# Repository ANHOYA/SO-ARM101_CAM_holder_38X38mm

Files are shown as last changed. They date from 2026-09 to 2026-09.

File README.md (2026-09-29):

# 38 mm IMX307 Camera Mounts for SO-101 and 1/4-20 Tripods

Printable mounts for a **38 × 38 mm IMX307 USB camera board**: a wrist mount for the SO-101 follower arm and two versions of a tripod / ball-head holder with a standard 1/4-20 camera screw. Check the dimensions below before printing; the IMX307 sensor name alone does not guarantee that another camera board will fit.

## Downloads

| File | Use |
| --- | --- |
| [`SO101_wrist_IMX307_38mm.stl`](SO101_wrist_IMX307_38mm.stl) | Attaches the camera to the **SO-101 follower wrist** using the wrist's two M3 nut recesses. |
| [`Tripod_IMX307_38mm_quarter20_nut.stl`](Tripod_IMX307_38mm_quarter20_nut.stl) | **Tripod v1:** compact base; 6 mm horizontal offset to the nut axis and a 4 mm nut-pocket floor. |
| [`Tripod_IMX307_38mm_quarter20_nut_v2.stl`](Tripod_IMX307_38mm_quarter20_nut_v2.stl) | **Tripod v2:** 18 mm horizontal offset to the nut axis for more access, with a thinner 2 mm nut-pocket floor. |

All STL files use **millimetres**. Choose one mount for each camera. Both tripod versions require a separate metal **1/4-20 UNC hex nut** to provide the female thread; the printed parts have no thread. It is not compatible with an M6 nut.

## Photos

SO-101 wrist installation with the intended 38 × 38 mm camera board:

### SO-101 wrist mount

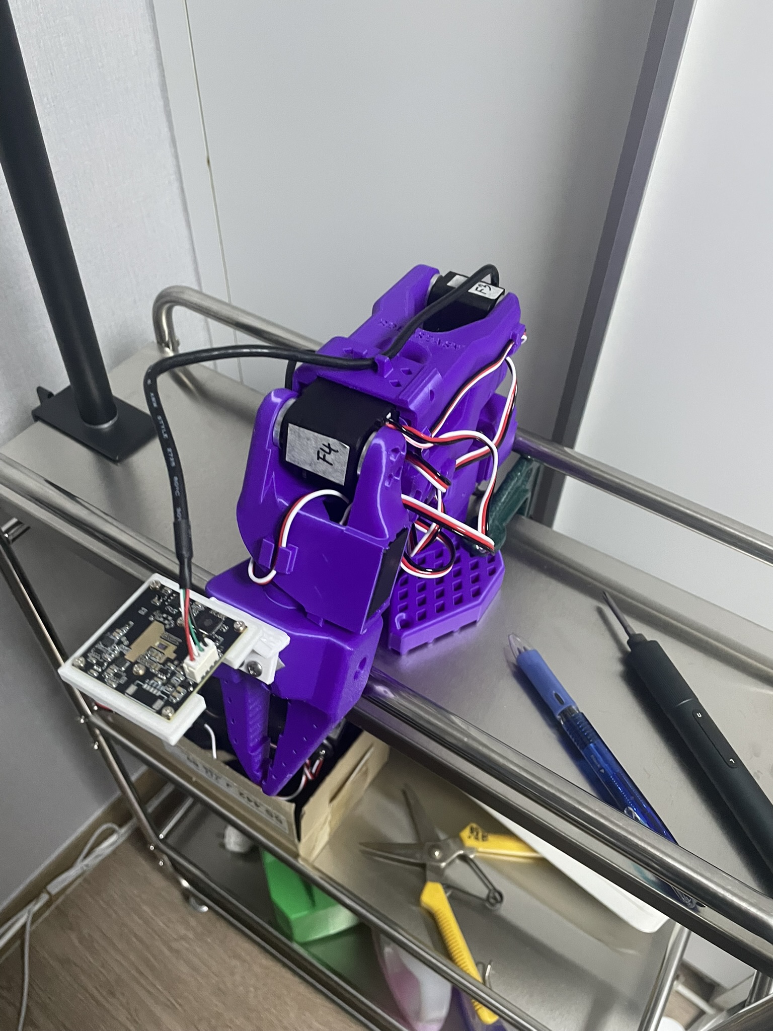
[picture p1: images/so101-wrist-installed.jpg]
38 mm IMX307 camera installed on the SO-101 wrist
 

### Tripod / ball-head mount

Mount on ball-head mount before installing the camera module
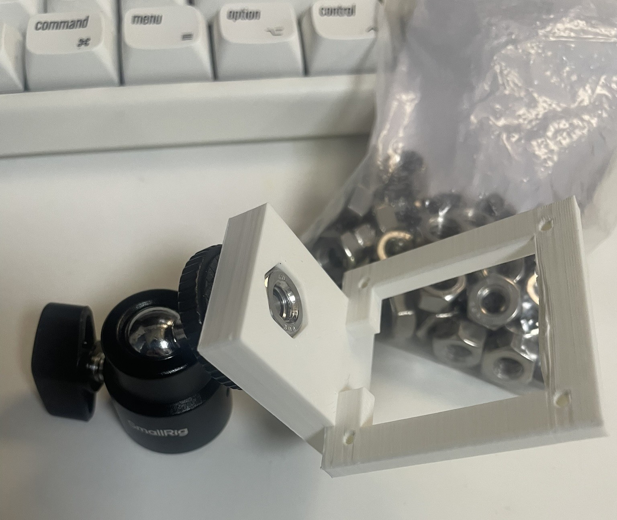
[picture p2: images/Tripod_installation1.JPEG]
38 mm IMX307 camera installed on ball-head mount
 

Tripod & Ball-head mount
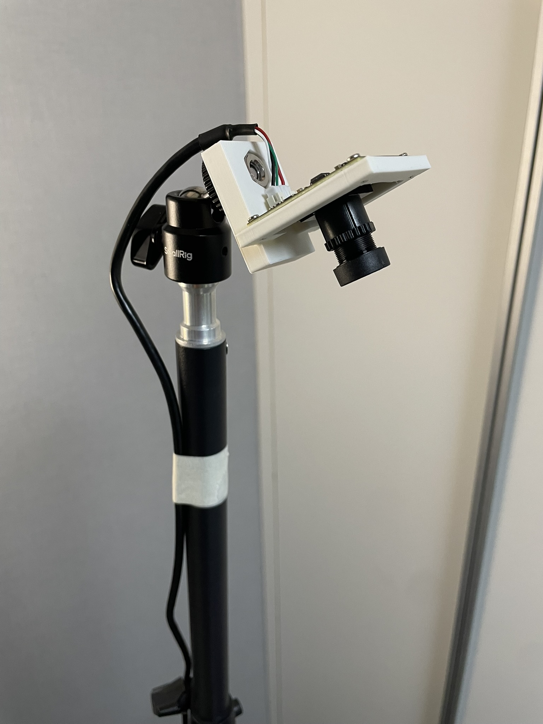
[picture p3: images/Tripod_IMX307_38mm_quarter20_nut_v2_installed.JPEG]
38 mm IMX307 camera installed on tripod&ball-head mount
 

## Camera board compatibility

The mounts were designed from the supplied camera drawing, not from the IMX307 chip specification.

| Feature | Required / design value |
| --- | ---: |
| PCB width × height | **38 × 38 mm** |
| PCB thickness | **1.6 mm** |
| Mounting holes | **4 holes, Ø2 mm** |
| Hole centres | **34 × 34 mm**, centre to centre |
| Hole centre from each PCB edge | **2 mm** |
| Camera frame outside size | 44 × 44 mm |
| Camera frame opening | 30 × 30 mm, with a 14 mm wide opening at the bottom for the cable/connector area |
| Camera frame thickness | 4.2 mm |

The camera board sits **behind the frame**, with the lens pointing through its central opening. Four M2 screws secure it through the PCB mounting holes. The back is open for the connector and cable. The drawing also shows approximately 23.5 mm of lens projection and a 6 mm rear connector projection; measure other components and cable clearance on your actual camera before use.

These are open mounting frames, not sealed camera enclosures. A 38 × 38 mm board with a different lens housing, connector position, or component placement may need a modified opening.

## SO-101 wrist holder

The wrist holder fits the **SO-101 follower wrist with two M3 nut recesses**. It adapts the original 32 mm camera mount to a 38 mm camera board while keeping the robot-side attachment geometry and the orientation of the camera mounting face.

| Feature | Specification |
| --- | --- |
| Camera PCB | 38 × 38 mm, 1.6 mm thick |
| Camera PCB holes | Four Ø2 mm holes on a 34 × 34 mm centre-to-centre pattern |
| Printed camera frame | 44 × 44 mm, 4.2 mm thick |
| Frame opening | 30 × 30 mm, with a 14 mm wide bottom cable relief |
| Camera fastening | Four M2 screws; Ø1.8 mm pilot holes in the printed frame |
| Robot fastening | Two M3 × 8 mm screws and two M3 hex nuts |
| Compatible wrist | SO-101 follower; not the SO-100 wrist |

The camera sits behind the frame with the lens pointing through the opening. The wrist holder is unchanged by the tripod v2 update.

## Tripod holder: v1 and v2

Both versions fit the same camera board and use the same metal 1/4-20 nut. **v2 moves the nut horizontally away from the camera plate**, toward the back of the PCB, to give more room when tightening or loosening the connection. It also halves the floor thickness below the nut so a short ball-head screw can reach farther into the thread.

| Dimension | Tripod v1 | Tripod v2 |
| --- | ---: | ---: |
| Horizontal distance from PCB front mounting plane to nut axis | 6 mm | **18 mm** |
| Camera PCB bottom to base top | 1 mm | **1 mm** |
| Material below the nut | 4 mm | **2 mm** |
| Nut-pocket depth | 6 mm | 6 mm |
| Nut-pocket width across flats | 11.5 mm | 11.5 mm |
| Bolt clearance hole | Ø6.8 mm | Ø6.8 mm |
| Base width × depth × thickness | 28 × 26 × 10 mm | 28 × 38 × 8 mm |
| Overall width × depth × height | 44 × 26 × 52 mm | 44 × 38 × 50 mm |

The horizontal nut offset increases by **12 mm**. The camera-to-base vertical spacing and the nut-seat height relative to the camera remain the same as v1. The overall height decreases by 2 mm because the underside is thinner.

Use v1 if its compact base and screw engagement suit your setup. Choose v2 when you need more access around the nut or when the v1 floor prevents your ball-head screw from reaching the nut. With the same screw projection, v2 provides **2 mm more available thread engagement**; confirm the actual fit with your ball head.

## Hardware

**All mounts:** four M2 camera screws. M2 × 5 mm is a starting point for the 1.6 mm PCB and 4.2 mm frame; confirm the usable length against your screw heads and camera components. The printed holes are Ø1.8 mm pilot holes. Tap them for M2 or use appropriate screws for your print material; tighten only enough to secure the PCB.

**SO-101 wrist:** two M3 × 8 mm screws and two M3 hex nuts for the robot attachment, as in the [original SO-101 hex-nut wrist mount instructions](https://github.com/TheRobotStudio/SO-ARM100/blob/main/Optional/SO101_Wrist_Cam_Hex-Nut_Mount_32x32_UVC_Module/README.md). This model targets the **SO-101 follower**, not the SO-100 wrist.

**Tripod / ball head — both v1 and v2:** Insert one metal **1/4-20 UNC hex nut**, approximately 11.11 mm across flats and up to 5.6 mm thick, into the top-open pocket. The pocket is 11.5 mm across flats and 6 mm deep. The bolt passes through a Ø6.8 mm clearance hole from below. The metal nut supplies the thread; the printed part is not threaded. Check the actual screw engagement when assembling.

The material below the nut is **4 mm in v1 and 2 mm in v2**. A small amount of adhesive at the pocket wall can keep the nut from falling out when the ball head is removed. Keep adhesive out of the threads and avoid overtightening against the thinner v2 floor.

## Printing and installation

Suggested starting settings: PLA or PETG, 0.2 mm layers, four walls, approximately 40% infill. Orient the **tripod mount with its base on the build plate**. Place the **wrist mount in a stable orientation** in your slicer and add supports where its angled arm needs them; the original design recommends tree supports. Check the preview for the centre opening, M2 holes and nut pocket before printing.

Attach the camera from the back of the frame. For the wrist mount, follow the [original installation sequence](https://github.com/TheRobotStudio/SO-ARM100/blob/main/Optional/SO101_Wrist_Cam_Hex-Nut_Mount_32x32_UVC_Module/README.md) for the SO-101 nut recesses and wrist screws. For the tripod mount, insert the metal nut before connecting the ball head. Route the camera cable so it does not pull on the PCB or enter the robot's moving parts.

**Fit tip from my build:** I added one layer of double-sided tape between the mating surfaces to remove a little play during installation. The spare screws supplied in the motor box also worked well for fastening the mount. Check their thread size and length against the holes and hardware listed above before tightening; the tape is a shim, not a substitute for the screws.

The STL meshes were checked as closed, single-body models. The maker has confirmed the wrist holder and the original tripod holder fit the intended camera; the tripod v1 connection can still have limited access or insufficient screw engagement with some ball heads. The v2 exported STL was also checked for its 2 mm nut floor and open screw passages. **Physical fit of v2 has not yet been confirmed.** Other camera variants and printer tolerances have not been checked.

## Design origin and licence

The wrist model modifies [TheRobotStudio's SO-ARM100 / SO-101 hex-nut wrist camera mount](https://github.com/TheRobotStudio/SO-ARM100/tree/main/Optional/SO101_Wrist_Cam_Hex-Nut_Mount_32x32_UVC_Module), originally made for a 32 × 32 mm camera. Its robot-side mounting geometry and camera-face orientation were retained; the camera frame was enlarged for a 38 × 38 mm board, its holes moved to a 34 × 34 mm pattern, and local PCB clearance was added. The tripod mount was designed separately for this camera drawing.

The original wrist mount is [Apache-2.0 licensed](https://github.com/TheRobotStudio/SO-ARM100/blob/main/LICENSE); its licence is included as [`LICENSE_original.txt`](LICENSE_original.txt).

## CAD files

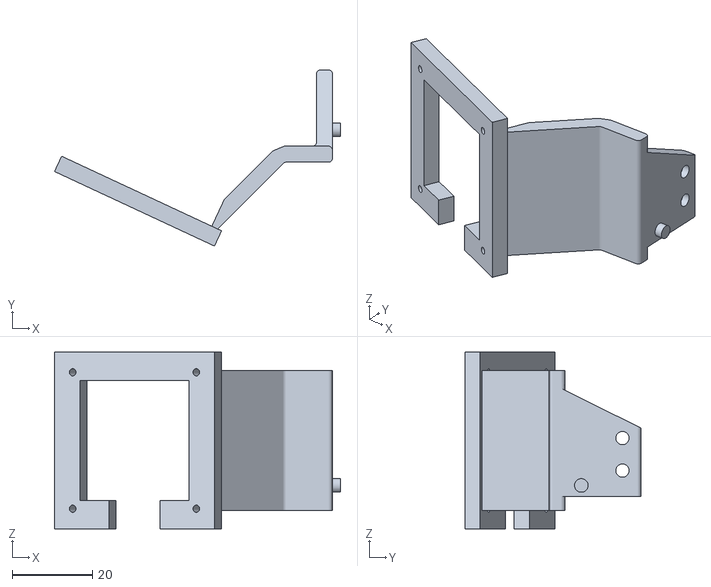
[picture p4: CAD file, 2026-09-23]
SO101_wrist_IMX307_38mm.stl
71.3 x 43.9 x 44.0

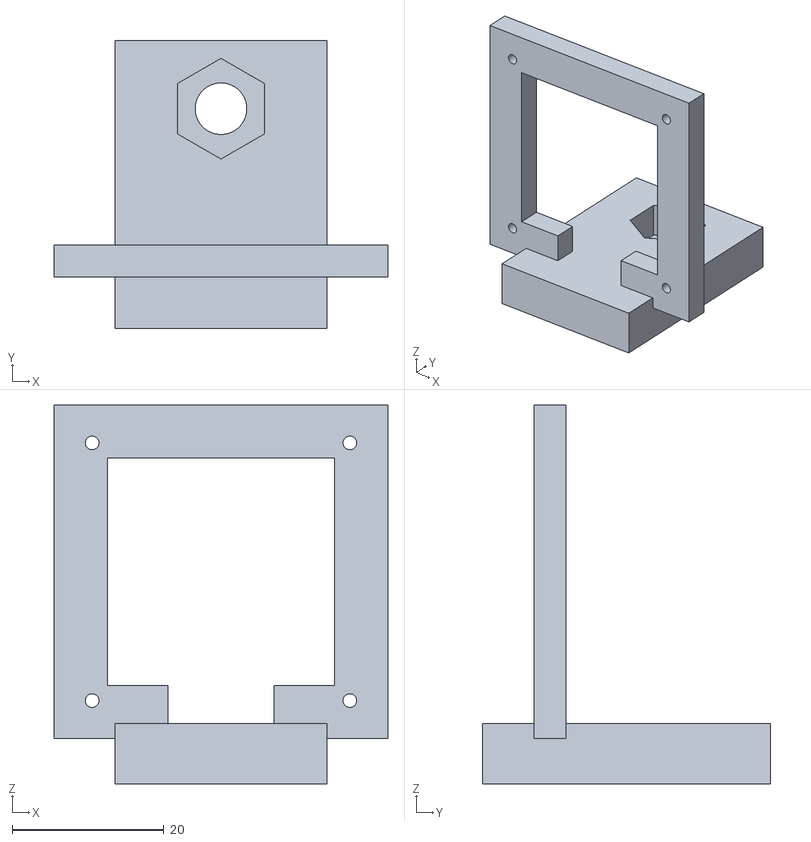
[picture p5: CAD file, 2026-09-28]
Tripod_IMX307_38mm_quarter20_nut_v2.stl
44.0 x 38.0 x 50.0

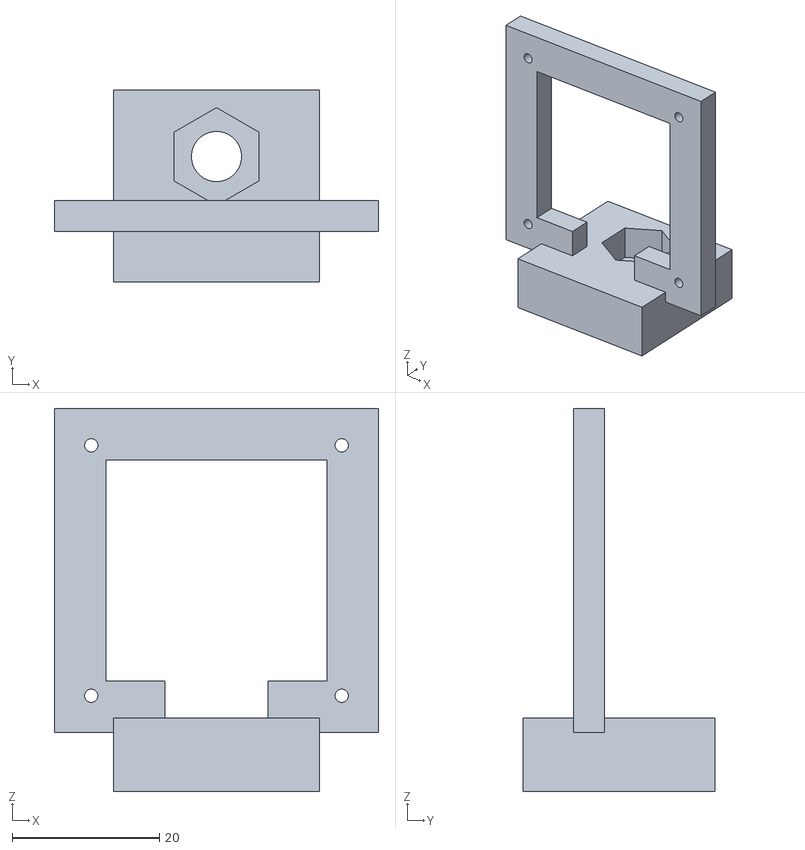
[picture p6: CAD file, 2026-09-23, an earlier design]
Tripod_IMX307_38mm_quarter20_nut.stl
44.0 x 26.0 x 52.0

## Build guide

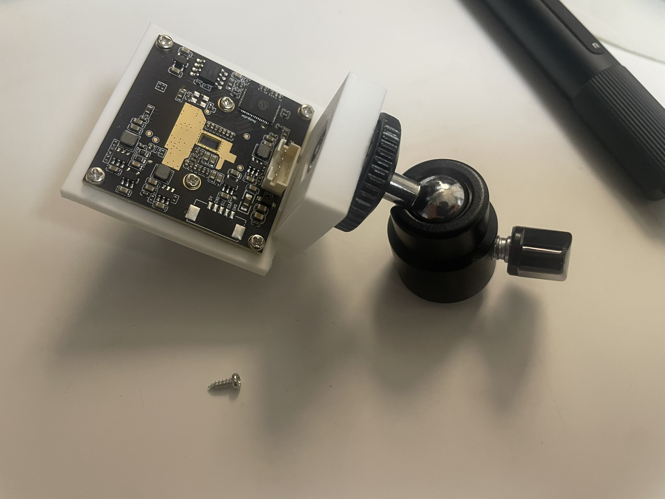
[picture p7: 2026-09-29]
images/Tripod_installation2.JPEG
